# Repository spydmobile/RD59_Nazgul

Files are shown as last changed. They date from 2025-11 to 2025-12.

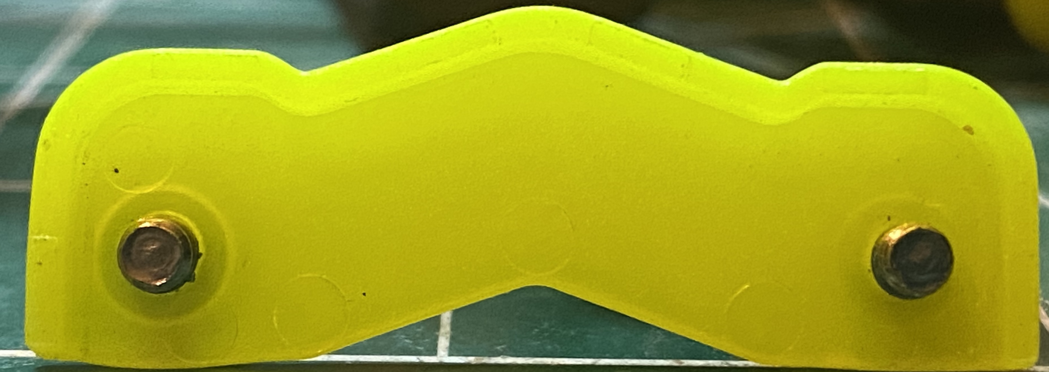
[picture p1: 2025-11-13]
custom parts/IMG_5613.jpg

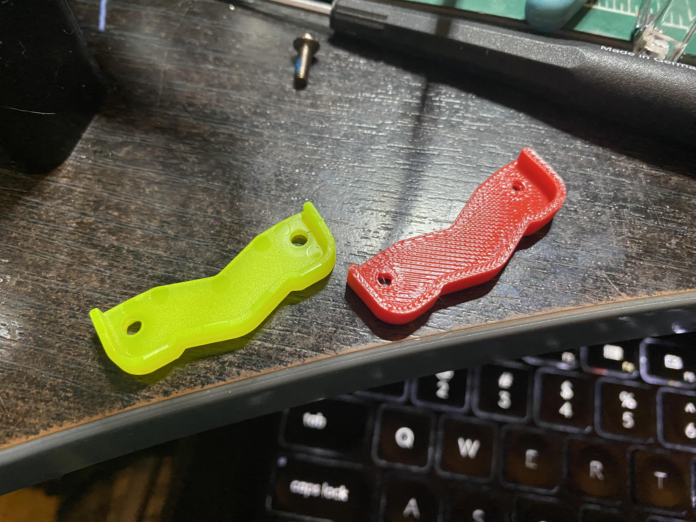
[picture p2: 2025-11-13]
custom parts/duped.jpg

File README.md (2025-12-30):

# RD-59 "Nazgul" Documentation Repository

**Drone Designator**: RD-59
**Code Name**: Nazgul
**Operator**: SpyD (Franco Nogarin)
**Platform**: Nazgul DC5 ECO V1.1 - 5" Freestyle Quadcopter

This repository serves as the **authoritative source of truth** for RD-59 "Nazgul" - a Nazgul DC5 ECO V1.1 acquired from Devon "Toasty" Felker on July 15, 2025.

---

## 🚨 Current Status

| Status | Value |
|---|---|
| **Airworthiness** | ❌ NOT AIRWORTHY (VTX swap in progress) |
| **VTX Status** | TX800 removed (Dec 30, 2025) - failed bench test Nov 14. Harness + antenna still installed. |
| **Next Step** | Install GEPRC RAD Mini 1W (on hand) |
| **Acquisition Date** | July 15, 2025 |
| **Test Flights** | 0 (not yet flown by current operator) |
| **Incidents** | 0 |
| **Modifications** | 1 completed (RX), 1 in progress (VTX swap), 2 pending |

---

## 📖 Origins

**Acquisition Story**:

This aircraft was purchased from **Devon "Toasty" Felker** in Hay River on **July 15, 2025** for **$273.12 CAD**.

The aircraft is a **Nazgul DC5 ECO V1.1** (iFlight pre-built 5" freestyle drone) that was sold as a **partial build**:

- **Removed by previous owner**: DJI O4 Air Unit Pro (camera + VTX)
- **Never included**: Receiver (not part of factory package)
- **Included**: Frame, flight controller, ESC, motors, GPS, props, battery connector

This is where RD-59 Nazgul's story with the current operator begins.

---

## 📚 Documentation

Complete technical documentation is maintained in the `/Documentation/` directory:

### 📋 Core Documents

- **[Documentation/README.md](./Documentation/README.md)** - Documentation hub and quick reference
- **[RD-59_AsBuilt_Parts_List.md](./Documentation/RD-59_AsBuilt_Parts_List.md)** - Current configuration and component inventory
- **[RD-59_Incident_Log.md](./Documentation/RD-59_Incident_Log.md)** - Crash reports and damage tracking
- **[RD-59_Modifications_Log.md](./Documentation/RD-59_Modifications_Log.md)** - Engineering changes and upgrades
- **[RD-59_Build_Timeline.md](./Documentation/RD-59_Build_Timeline.md)** - Project history and milestones

### 📖 Reference Materials

- **[Factory Specifications](./Documentation/reference/Nazgul_DC5_ECO_Factory_Specs.md)** - Original iFlight specifications

### 🔗 External Resources

- **Photo Gallery**: [Google Photos Album](https://photos.google.com/album/AF1QipMQ81SgmNKcywQYFzFxxncO6l4DfiegxZddzp05)
- **Local Photos**: `/Users/franconogarin/localcode/spyd.com/public/drone-lab/drones/RD-59/`

---

## 🎯 Quick Links

**Starting Point**: 👉 [**Documentation/README.md**](./Documentation/README.md)

**Need to know**:

- Current configuration? → [As-Built Parts List](./Documentation/RD-59_AsBuilt_Parts_List.md)
- Crash history? → [Incident Log](./Documentation/RD-59_Incident_Log.md)
- Modifications made? → [Modifications Log](./Documentation/RD-59_Modifications_Log.md)
- Project timeline? → [Build Timeline](./Documentation/RD-59_Build_Timeline.md)

---

## 🚀 Next Steps to Airworthiness

**Current State**: TX800 failed bench test (Nov 14) and removed (Dec 30). Camera, harness, and antenna remain installed. RAD Mini ready.

### Phase 1: Critical (VTX Swap)

1. ✓ **Install Receiver** (MOD-001) - HappyModel ELRS EP1 Dual RX - COMPLETE
2. ⚠️ **VTX Swap** (MOD-002A) - TX800 FAILED → GEPRC RAD Mini 1W
   - ✓ TX800 removed (Dec 30, 2025)
   - ✓ Ratel 2 camera installed
   - ✓ Harness + TrueRC antenna in place
   - ⏳ Install RAD Mini (rewire power from 5V to VBAT)
   - ⏳ Bench test video
   - ⏳ Bind ELRS receiver
3. **Test flights** - Establish baseline with analog system

### Phase 1B: Optional Digital Upgrade (If Analog Insufficient)

- **Walksnail Avatar HD** (MOD-002B) - on hand as backup if needed
- Trade-off: Better video quality, but 40-50% flight time penalty

### Phase 2: Optional Enhancements (After Flying)

1. *Optional*: Install RGB LEDs (MOD-003)
2. *Optional*: Install GPS-mate (MOD-004)

**Status**: RAD Mini on hand. Swap requires power wire move (5V → VBAT) then bench test.

See [Modifications Log](./Documentation/RD-59_Modifications_Log.md) for detailed installation checklists and analog vs digital comparison.

---

## ℹ️ Important Notes

- **Source of Truth**: This repository contains verified technical specifications
- **Partial Build**: Aircraft acquired without video system or receiver
- **RX Installed**: ELRS EP1 Dual RX installed Nov 13, 2025 - needs binding
- **VTX Swap In Progress**: TX800 failed (Nov 14) and removed (Dec 30). RAD Mini ready to install.
- **Untested**: Not yet flown by current operator since acquisition

---

## 📧 For Claude Code Assistants

See **[CLAUDE.md](./CLAUDE.md)** for detailed instructions on:

- Your role as RD-59 Archivist & SME
- Documentation standards and procedures
- How to work with the operator
- Repository structure and guidelines

---

**Repository Established**: November 10, 2025
**Maintained by**: SpyD (Franco Nogarin) with Claude Code

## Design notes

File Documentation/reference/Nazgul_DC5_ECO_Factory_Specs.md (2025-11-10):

# Nazgul DC5 ECO V1.1 6S HD O4 - Factory Specifications

**Reference Document**: Original factory specifications from iFlight

**Product Name**: Nazgul DC5 ECO 6S O4 HD - ELRS + GPS

---

## Overview

The Nazgul DC5 ECO is a 5-inch freestyle drone that redefines performance and value for money. Equipped with the DJI O4 Digital HD system, it delivers razor-sharp, propeller-free 4K video even in low light conditions. The robust carbon frame and aluminum camera mount guarantee durability without sacrificing lightness. The pre-installed GoPro mount makes the drone even more versatile.

Thanks to the BLITZ ATF435 flight controller and the powerful BLITZ E55S ESC, the Nazgul DC5 ECO offers a reliable and dynamic flying experience. With a maximum speed of 190 km/h and an optimized DeadCat design, this drone is perfect for FPV pilots looking for performance and quality.

---

## Features

- **4K Ultra HD video**: DJI O4 system with 1/1.3-inch sensor for stunning footage and stable 155° ultra-wide angle video
- **Robust and lightweight**: High-quality carbon frame with aluminum components for a stable construction
- **Anti-Spark technology**: Protects the electronics from power surges and extends the life of the XT60 connectors
- **Optimized DeadCat design**: No disturbing propellers in the camera image - ideal for professional aerial photography
- **Easy maintenance**: Built-in signaling devices and easily accessible components ensure convenient handling

---

## General Specifications

| Specification | Value |
|---|---|
| **Product name** | Nazgul DC5 ECO 6S O4 HD |
| **Geometry** | DeadCat (DC) |
| **Frame** | 240 mm wheelbase |
| **Weight** | 450g ±5g (without battery) |
| **Take-off weight** | Approx. 675g ±5g (with 6S 1480mAh battery) |
| **Dimensions (L×W×H)** | 193 × 144 × 34 mm |
| **Max. speed** | 190 km/h |
| **Max. hover time** | Approx. 7.5 minutes (6S 1480mAh, without load) |
| **Maximum flight altitude** | 7000 m |
| **Wind resistance** | Up to level 7 |
| **Temperature range** | -10 °C to 40 °C |

---

## Electronics

| Component | Specification |
|---|---|
| **Flight controller** | BLITZ ATF435 |
| **ESC** | BLITZ E55S 4-in-1 ESC |
| **Motors** | XING-E Pro 2207 1800KV |
| **Propeller** | Nazgul F5 |
| **GPS** | Yes |
| **Battery Connector** | XT60 with anti-spark technology |

---

## Video Transmission - DJI O4 Air Unit Pro

| Specification | Value |
|---|---|
| **Sensor** | 1/1.3-inch |
| **Video resolution** | 4K at 30fps, 1080p at 100fps |
| **Field of view (FOV)** | 155° |
| **Stabilization** | RockSteady 3.0+ |
| **Video Quality** | 1080P@100fps |
| **Max. video transmission range** | Up to 15 km (FCC) |
| **Operating frequencies** | 5.170-5.850 GHz |
| **Built-in memory** | 4GB |

---

## Package Contents

- 1 x Nazgul ECO
- 2 x Battery pads
- 2 x Nazgul F5 Prop (Pairs)

---

## Important Notes

**Factory Configuration**:
- This specification represents the drone as sold by iFlight
- Product includes DJI O4 Air Unit Pro as standard
- GPS module included
- **Receiver NOT included** - must be purchased separately

**RD-59 As-Purchased**:
- DJI O4 system was removed by previous owner before sale
- No receiver was ever installed (not included by factory)
- See `RD-59_AsBuilt_Parts_List.md` for actual acquired configuration

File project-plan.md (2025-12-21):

# Project Plan: RD59 Nazgul

**Project:** RD59_Nazgul
**Owner:** Circuit (Fleet Steward)
**Created:** December 21, 2025
**Status:** Not Airworthy (Missing Critical Systems)

---

## Overview

RD59 "Nazgul" is a 5" freestyle quad acquired as a partial build. The DJI O4 video system was removed by the previous owner, and no receiver was ever installed. Critical systems pending installation.

**Repository:** `spydmobile/RD59_Nazgul`
**Location:** `projects/drone_management/drones/RD59_Nazgul/`
**Platform:** 5" Freestyle (iFlight Nazgul DC5 ECO V1.1)

---

## Current State

| Attribute | Value |
|---|---|
| **Airworthiness** | NOT AIRWORTHY |
| **Acquisition Date** | July 15, 2025 |
| **Days Since Acquisition** | 159 days |
| **Previous Owner** | Devon "Toasty" Felker |
| **Flight Hours (Current Owner)** | 0.0 |
| **Video System** | REMOVED (was DJI O4) |
| **Control Link** | NOT INSTALLED |

**Operational Components:**
- Frame (Nazgul DC5 240mm DeadCat)
- FC (BLITZ ATF435 - untested)
- ESC (BLITZ E55S 4-in-1 60A - untested)
- Motors (XING-E Pro 2207 1800KV x4 - untested)
- GPS (iFlight - operational)
- Props (Nazgul F5)

**Missing Components:**
- Receiver (never included)
- Video system (stripped by previous owner)

---

## Milestones

### Milestone 1: Acquisition (COMPLETE)
**Status:** Complete | **Date:** July 15, 2025

- [x] Purchased from Devon Felker
- [x] Documented as-received condition
- [x] Created documentation structure
- [x] Photographed aircraft

### Milestone 2: Phase 1 Parts (COMPLETE)
**Status:** Complete | **Date:** July 24, 2025

Parts on hand, installation pending.

- [x] Order ELRS receiver (HappyModel EP1 Dual)
- [x] Order analog VTX (SpeedyBee TX800)
- [x] Order analog camera (CADDX Ratel 2)
- [x] Parts received

### Milestone 3: Phase 1 Installation (PENDING)
**Status:** Pending | **Priority:** CRITICAL

Get aircraft flying with analog video for maximum flight time.

- [ ] Install HappyModel ELRS EP1 Dual receiver (MOD-001)
- [ ] Install SpeedyBee TX800 VTX (MOD-002A)
- [ ] Install CADDX Ratel 2 camera
- [ ] Route antennas
- [ ] Configure Betaflight
- [ ] Bind ELRS receiver
- [ ] Bench test all systems
- [ ] First hover test
- [ ] Maiden FPV flight

### Milestone 4: Phase 1B Digital Upgrade (OPTIONAL)
**Status:** Optional | **Priority:** Low

Only if analog insufficient after test flights.

- [ ] Evaluate analog performance
- [ ] Decision: Keep analog or upgrade?
- [ ] If upgrade: Install Walksnail Avatar HD Moonlight (MOD-002B)
- [ ] Note: Digital reduces flight time (5-7 min → 3-5 min)

### Milestone 5: Phase 2 Enhancements (PENDING)
**Status:** Pending | **Priority:** Low

Install after test flights prove platform viability.

- [ ] Install SpeedyBee RGB LEDs (MOD-003)
- [ ] Install VIFLY GPS-mate with Finder 2 (MOD-004)

---

## GitHub Issues

| # | Title | Labels | Priority |
|---|---|---|---|
| 1 | Install HappyModel ELRS EP1 Dual RX receiver | pending-install, radio-system | CRITICAL |
| 2 | Select and install replacement FPV video system | enhancement, video-system | CRITICAL |

---

## Current Tasks

| Task | Priority | Status |
|---|---|---|
| Install ELRS receiver | CRITICAL | Parts in hand |
| Install analog VTX/camera | CRITICAL | Parts in hand |
| Betaflight configuration | High | After installation |
| First flight test | High | After config |
| Evaluate analog performance | Medium | After flights |

---

## Installation Strategy

**Phase 1: Minimum Viable Aircraft**
1. Install receiver (ELRS EP1 Dual) - control link
2. Install analog VTX (TX800) + camera (Ratel 2) - video link
3. Get flying, evaluate performance

**Why Analog First:**
- Longer flight time (5-7 min vs 3-5 min with digital)
- Lower power consumption
- Parts already on hand
- Can upgrade later if needed

**Phase 1B Decision Point:**
After 5-10 test flights, evaluate:
- Is analog video quality acceptable?
- Is 5-7 min flight time sufficient?
- If no: upgrade to Walksnail (MOD-002B)

---

## Operations

**Documentation:**
- Parts List: `Documentation/RD-59_AsBuilt_Parts_List.md`
- Timeline: `Documentation/RD-59_Build_Timeline.md`
- Modifications: `Documentation/RD-59_Modifications_Log.md`
- Installation Guide: `Documentation/RD-59_Phase1_Installation_Guide.md`

**Pre-acquisition history:**
- Previous owner flight history: Unknown
- Previous incidents: Unknown
- All electronics untested by current operator

---

*Circuit - Fleet Steward*

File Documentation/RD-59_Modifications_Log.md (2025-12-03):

# RD-59 "Nazgul" Modifications Log

**Drone Designator**: RD-59
**Code Name**: Nazgul
**Operator**: SpyD (Franco Nogarin)
**Last Updated**: 2025-12-02

---

## Modification Summary

| Total Modifications | Last Modification Date | Current Status |
|---|---|---|
| **1 completed, 1 in progress, 3 pending** | GEPRC RAD arrived Dec 2, 2025 | Analog video confirmed |

**Installation Plan**:

- **Phase 1 (Critical)**: MOD-001 (✅ installed) + MOD-002A (analog - GEPRC RAD) → Get aircraft flying
- **Phase 1B (Backup Only)**: MOD-002B (Walksnail) → Only if analog performance insufficient
- **Phase 2 (Optional Enhancements)**: MOD-003 + MOD-004 → Add LEDs and GPS-mate after baseline established

**Decision (Dec 2, 2025)**: HDZero VTX (MOD-002C) reallocated to RD-54 "Zorro". RD-59 confirmed for analog to maximize flight time.

---

## Planned Modifications

### PHASE 1: CRITICAL AIRWORTHINESS INSTALLATIONS

**Objective**: Install receiver and video system to achieve minimum flight capability

### MOD-001: ELRS Receiver Installation

**Status**: 🟢 **COMPLETED** - Installed November 13, 2025
**Type**: Initial Installation
**Priority**: CRITICAL (required for airworthiness)
**Parts Acquired**: June 4, 2025 (already owned before drone acquisition)
**Installation Date**: November 13, 2025

#### Description

Installation of ExpressLRS receiver system to enable aircraft control.

#### Modification Details

| Item | Original Config | Modified Config |
|---|---|---|
| **Receiver** | None (never included) | HappyModel ExpressLRS TCXO EP1 Dual RX |
| **Control Link** | None | ExpressLRS 2.4GHz |
| **Antenna** | None | Included with EP1 Dual RX |

#### Rationale

- Aircraft was purchased without receiver (not included in factory package)
- Receiver is critical component for aircraft control
- ELRS selected for low latency, long range, and reliability
- EP1 Dual RX provides redundancy with dual antenna diversity
- Already owned this receiver prior to acquiring RD-59

#### Expected Impact

- Enable aircraft control capability
- Required for test flights
- Minimal weight impact (~1-2g)
- Dual receiver provides improved range and reliability

#### Parts On Hand

- [x] HappyModel ExpressLRS TCXO EP1 Dual RX (acquired June 4, 2025)
- [x] Antennas (included with receiver)

#### Installation Checklist

**UART Selection** (from BLITZ ATF435 wiring diagram):

- **Recommended**: UART2 (R2/T2 pads) - shown in diagram for ELRS receiver
- **Alternative UARTs available**: UART1 (R1/T1), UART3 (R3/T3), UART4 (R4/T4), UART5 (R5/T5), UART6 (R6)

**Wiring Connections**:

- [ ] Solder RX wire to T2 pad (FC transmits to receiver)
- [ ] Solder TX wire to R2 pad (FC receives from receiver)
- [ ] Solder VCC wire to 5V pad (receiver power)
- [ ] Solder GND wire to GND pad (ground)

**Physical Installation**:

- [ ] Determine mounting location (typically between FC and camera mount)
- [ ] Mount HappyModel EP1 Dual RX receiver with double-sided tape or heat shrink

**Dual Antenna Routing Strategy**:

The HappyModel EP1 Dual RX has two T-shaped antennas for diversity reception. The Nazgul was originally designed for DJI O4's antenna configuration, so custom routing is required for optimal dual-antenna diversity.

**Critical Antenna Diversity Principles**:

- ✅ **90° separation**: Antennas must be perpendicular to each other (NOT parallel)
- ✅ **Physical separation**: Mount at different locations on frame
- ✅ **Minimize carbon fiber contact**: CF blocks 2.4GHz signal - maintain 5-10mm clearance minimum
- ✅ **Secure firmly**: Heat shrink/zip ties prevent antenna movement into props
- ✅ **Top mounting preferred**: Less carbon fiber interference than bottom mounting
- ❌ **Never parallel**: Defeats dual diversity purpose
- ❌ **Never touching carbon fiber**: Causes major signal degradation

**Primary Antenna (Antenna 1) - Rear Vertical**:

- [ ] Route through rear of frame (where DJI O4 antenna previously exited, or near GPS)
- [ ] Position **vertically** or angled back/up at 30-45° (perpendicular to drone body)
- [ ] Use existing antenna mount hole if available, or create exit point
- [ ] Heat shrink antenna base to frame standoff or rear for stability
- [ ] Ensure antenna extends beyond frame and clears carbon fiber by 5-10mm minimum

**Secondary Antenna (Antenna 2) - Rear Side Top (RECOMMENDED)**:

**Option 3: Rear Side Top** ✅ **BEST CONFIGURATION**

- [ ] Mount T-antenna **horizontally** (parallel to drone body) on top of frame
- [ ] Position beside or slightly forward of VTX location
- [ ] Maintain **10-15mm clearance from VTX** to minimize RF interference
- [ ] Orient T-antenna so it's **perpendicular to primary antenna** (90° diversity)
- [ ] Ensure antenna tips **do not touch carbon fiber arms** (maintain 5-10mm gap)
- [ ] Use heat shrink or small zip tie to secure to frame standoff or top plate
- [ ] Verify antenna tips have clearance from props during flight

**Why Option 3 (Rear Side Top) is Optimal**:

- Top mounting = minimal carbon fiber interference (best signal propagation)
- Rear location = away from front props (DeadCat has most prop activity forward)
- Physical separation from primary antenna = improved diversity
- Horizontal T gives 90° diversity from vertical primary
- Less vulnerable to ground strikes vs bottom mounting
- Good separation from electrical noise sources (ESC/battery)

**Alternative Options Evaluated** (use only if Option 3 not feasible):

*Option 1: Side Bottom (Under FC)* - ❌ **NOT RECOMMENDED**

- Antenna tips touch CF arms = major signal loss
- Maximum carbon fiber interference
- Vulnerable to ground strikes

*Option 2: Side Top (Above FC, between arms)* - ⚠️ **MARGINAL**

- Better than bottom, but antenna tips still touch/near CF arms
- Props directly above = turbulence/strike risk

*Option 4: Rear Side Bottom (Under VTX)* - ❌ **NOT RECOMMENDED**

- Carbon fiber interference from bottom mounting
- Ground strike vulnerability
- Near battery/ESC electrical noise

**Final Antenna Installation Verification**:

- [ ] Verify 90° separation between primary (vertical) and secondary (horizontal) antennas
- [ ] Verify both antenna tips clear carbon fiber by 5-10mm minimum
- [ ] Verify neither antenna can reach prop paths during flight
- [ ] Verify antennas are secured and cannot move/vibrate loose
- [ ] Verify secondary antenna has 10-15mm clearance from VTX
- [ ] Take photos of final antenna routing for documentation

**Configuration & Testing**:

- [ ] Enable UART3 in Betaflight Ports tab
- [ ] Configure UART3 for Serial RX
- [ ] Set receiver protocol to CRSF (ExpressLRS)
- [ ] Bind receiver to transmitter
- [ ] Test control inputs (roll/pitch/yaw/throttle)
- [ ] Configure and test failsafe settings
- [ ] Verify signal strength and range (bench test)
- [ ] Verify RSSI display on OSD
- [ ] Update RD-59_AsBuilt_Parts_List.md

#### Installation Results (Completed November 13, 2025)

**UART Configuration:**

- ✅ **UART3 used** (R3/T3 pads) instead of recommended UART2
- Operator chose UART3 over UART2 (both equally valid for ELRS)

**Wiring Completed:**

- ✅ EP1 RX (blue wire) → FC T3 pad
- ✅ EP1 TX (blue wire with yellow ends) → FC R3 pad
- ✅ EP1 5V (red wire) → FC 5V pad
- ✅ EP1 GND (red wire with black ends) → FC GND pad
- Wire gauge: 24AWG silicone (signal wires), 24AWG stranded non-silicone (power)
- Wires twisted in pairs for EMI reduction
- All wires pre-tinned, soldered, and heat-shrunk

**Physical Installation:**

- ✅ EP1 receiver wrapped in heat shrink for protection
- ✅ Hot glued into Nazgul receiver bracket (reused DJI O4 mount)
- Mounting location: Original DJI receiver position

**Antenna Routing (Final Configuration):**

*Primary Antenna (Antenna 1):*

- ✅ **Horizontal orientation** (parallel to drone body)
- ✅ Rear exit
- ✅ **17.5mm clearance from carbon fiber** (exceeds 5-10mm spec)

*Secondary Antenna (Antenna 2):*

- ✅ **Vertical orientation** (up/down)
- ✅ Side position behind VTX
- ✅ **4mm clearance from carbon body** (marginal - just under 5mm spec)

**Diversity Configuration:**

- ✅ **90° separation achieved** (horizontal primary vs vertical secondary)
- ✅ Physical separation (rear vs side)
- ✅ Both antennas secured

**Deviations from Plan:**

- Changed from UART2 to UART3 (operator preference)
- Primary antenna horizontal instead of vertical (adapted to actual frame geometry)
- Secondary antenna vertical side mount (not rear side top Option 3, but still achieves 90° diversity)

**Notes:**

- No issues during soldering
- Photos taken of installation
- Configuration and binding deferred to next session

---

### MOD-002A: Analog Video System Installation (Initial)

**Status**: 🔵 **IN PROGRESS** - Hardware installed Nov 13, 2025; bench test FAILED Nov 14, 2025
**Type**: Initial Installation
**Priority**: CRITICAL (required for FPV operation)
**Parts Status**: Already owned (liberated from 3.5" build)
**Installation Date**: November 13, 2025
**Bench Test Date**: November 14, 2025
**Bench Test Result**: ❌ FAILED - VTX communication working, but no video output; excessive heat

#### MOD-002A Description

Installation of analog FPV system (SpeedyBee TX800 + CADDX Ratel 2) as initial video system to get aircraft flying quickly.

#### MOD-002A Modification Details

| Item | Original Config | Modified Config |
|---|---|---|
| **Video System** | DJI O4 Air Unit Pro (Digital HD) | Analog (TX800 + Ratel 2) |
| **Camera** | DJI O4 1/1.3" sensor, 155° FOV | CADDX Ratel 2 (red) |
| **VTX** | DJI O4 (5.170-5.850 GHz, 15km range) | SpeedyBee TX800 (5.8GHz, 25-800mW) |
| **Recording** | DJI O4 4GB onboard | None (analog) |

#### MOD-002A Rationale

- **Test with what's already owned**: TX800 and Ratel 2 already on hand (liberated from 3.5" build)
- **Get flying quickly**: Analog is lighter and faster to install
- **Better flight time**: ~5-7 min vs 3-5 min with digital (40-50% improvement)
- **Lighter weight**: ~25g vs ~70g for digital (45g savings)
- **Lower power draw**: ~1A vs ~2.5A for digital
- **Evaluate needs**: Test analog performance before committing to digital
- **TX800 redemption**: Previous underperformance on 3.5" suspected due to mounting without standoffs (shorting issues)
- **Proper installation this time**: Will use standoffs to prevent shorting as per manual

#### MOD-002A Expected Impact

- Enable FPV video capability (analog quality)
- Flight time: **5-7 minutes** freestyle (excellent)
- Range: **2-4km** at 800mW (sufficient for most flying)
- Weight impact: **+25g** (minimal)
- Power draw: **~1A** at 800mW (low)
- No onboard recording (trade-off for flight time)

#### MOD-002A Performance Comparison vs Digital

| Metric | Analog (MOD-002A) | Digital (MOD-002B) | Advantage |
|---|---|---|---|
| Weight | +25g | +70g | Analog: 45g lighter |
| Power | ~1A | ~2.5A | Analog: 1.5A less |
| Flight Time | 5-7 min | 3-5 min | Analog: +40-50% |
| Range | 2-4km | 3-6km | Digital: slightly better |
| Video Quality | Standard analog | HD digital | Digital: much better |
| Recording | No | Yes (HD) | Digital wins |
| Cost | $0 (owned) | $0 (owned) | Tie |

**Decision**: Start with analog, evaluate if digital upgrade is worth the flight time penalty

#### MOD-002A Parts On Hand

- [x] SpeedyBee TX800 VTX (liberated from 3.5" build)
- [x] CADDX Ratel 2 camera (red) (already owned)
- [x] VTX antenna (included with TX800)

#### MOD-002A Installation Checklist

**Pre-Installation Testing**:

- [ ] Bench test TX800 to verify not damaged from previous shorting issues
- [ ] Prepare TX800 mounting with proper standoffs (CRITICAL - avoid shorting!)
- [ ] Verify TX800 antenna connector is intact

**UART Selection for VTX Control** (from BLITZ ATF435 wiring diagram):

- **Recommended**: UART1 (R1/T1 pads) or UART3 (R3/T3 pads) for SmartAudio/Tramp
- **Note**: UART2 already reserved for ELRS receiver (MOD-001)
- **Alternative UARTs**: UART4 (R4/T4), UART5 (R5/T5), UART6 (R6) if needed

**Camera Installation**:

- [ ] Install camera mount on front of frame
- [ ] Mount CADDX Ratel 2 camera with appropriate angle (20-40° typical for freestyle)
- [ ] Wire camera to TX800 VTX (camera video out → VTX video in)

**VTX Installation**:

- [ ] Install TX800 VTX with standoffs (CRITICAL - prevents shorting to FC or frame)
- [ ] Verify standoffs provide clearance from all metal surfaces
- [ ] Position VTX for easy antenna access

**Wiring Connections - VTX to FC**:

- [ ] Solder VTX TX wire to R1 pad (for SmartAudio/Tramp control)
- [ ] Solder VTX RX wire to T1 pad (if bidirectional control needed)
- [ ] Solder VTX power (+) wire to VBAT pad (filtered battery voltage)
- [ ] Solder VTX ground (-) wire to GND pad

**Antenna & Finalization**:

- [ ] Route and secure VTX antenna away from carbon fiber
- [ ] Ensure antenna has clear path (not blocked by frame/props)
- [ ] Secure all wiring with heat shrink/tape
- [ ] Verify no wires touching propeller path

**Configuration & Testing**:

- [ ] Enable UART1 in Betaflight Ports tab
- [ ] Configure UART1 for VTX (SmartAudio/Tramp/IRC Tramp)
- [ ] Configure VTX table in Betaflight (5.8GHz bands/channels)
- [ ] Configure OSD layout (add battery voltage, RSSI, flight time, etc.)
- [ ] Test video feed with analog goggles
- [ ] Verify OSD elements display correctly
- [ ] Test VTX power level switching (25/200/800mW)
- [ ] Verify VTX channel/band switching via OSD
- [ ] Update RD-59_AsBuilt_Parts_List.md

#### Installation Results (Completed November 13, 2025)

**Camera Mount - Custom TPU V3:**

- ✅ Reverse-engineered Nazgul bumper from photos (GIMP → Inkscape → Bambu Slicer)
- ✅ Integrated with Printables Ratel 2 protective sleeve
- ✅ Built-in 15° compensation wedge for camera angle
- ✅ **Net camera angle: ~10° upward** (cruising configuration)
- ✅ Material: Bambu TPU (red), X1C + AMS, 0.16mm HQ, solid 4-wall construction
- ✅ Fits perfectly in aluminum DJI housing
- Source: https://www.printables.com/model/1339078-caddx-ratel-2-crash-protection-sleeve-tpu

**Hardware Installed:**

- ✅ CADDX Ratel 2 camera (red) - mounted in V3 custom bumper
- ✅ SpeedyBee TX800 VTX (5V powered, 3.7-5V input range)
- ✅ TrueRC CORE 85mm MMCX RHCP antenna (replaces damaged RD-53 antenna)

**Wiring Harness (Camera + VTX → FC):**

- ✅ Camera Red → FC 5V
- ✅ Camera Black → FC GND
- ✅ VTX Red → FC 5V (**NOT VBAT!** TX800 is 3.7-5V only)
- ✅ VTX Black → FC GND
- ✅ VTX Green (IRC Tramp RX) → FC T1 (UART1 TX)
- ✅ Wires: 24AWG, twisted, tinned, soldered, heat-shrunk
- ✅ Routed over top of FC (more room than between layers)

**VTX Antenna:**

- ✅ TrueRC CORE 85mm MMCX RHCP
- ✅ Mounted 45° angle out rear
- ✅ Custom TPU threaded screw mount (repurposed dual antenna hole)

**Physical Installation Status:**

- ✅ Soldering complete
- ✅ Camera/VTX mounted
- ✅ Antenna secured

#### Bench Test Results (November 14, 2025)

**Test Environment:**

- FC: BLITZ ATF435 running Betaflight 4.5.1 (released Jan 16, 2025)
- Power: USB only (5V)
- Goggles: Analog FPV goggles (testing on Raceband)
- Software: Betaflight Configurator 10.10.0

**Betaflight Configuration Steps:**

1. ✅ **Initial connection**: FC detected as IFLIGHT_BLITZ_F435
2. ✅ **Accelerometer calibration**: Completed successfully
3. ✅ **UART inspection**: Discovered old DJI O4 configuration still present
   - UART1 (serial 0) was set to VTX (MSP + Displayport) - DJI digital config
   - UART3 (serial 2) already configured for Serial RX (CRSF) - correct for ELRS
4. ✅ **VTX Table configuration**: Configured via CLI
   - 5 bands (Boscam A, B, E, Fatshark, Raceband)
   - 8 channels per band
   - 4 power levels: 25mW (PIT), 200mW, 400mW, 800mW (MAX)
   - Initial settings: Raceband 1 (5658MHz), Pit mode (25mW)
5. ❌ **UART1 protocol issue**: Initial config used wrong VTX protocol
   - CLI command attempted generic VTX (function 2048)
   - Should have been **VTX (IRC Tramp)** specifically
   - Corrected via Ports tab in Betaflight Configurator
6. ✅ **VTX communication established**: "Device ready: True" after correct protocol set
7. ❌ **Video output FAILED**: No video signal in goggles despite VTX communication working

**Problems Discovered:**

1. **VTX ran at full power initially (before pit mode config)**
   - Default VTX config had no power limits
   - VTX likely running at 800mW on USB before configuration
   - TX800 became **extremely hot** during initial USB connection
   - Heat persisted even after pit mode (25mW) configuration

2. **No video output**
   - VTX communication with FC: ✅ Working (IRC Tramp, Device ready: True)
   - VTX LED status: Red/blue flashing 1 per second (indicates no video input from camera)
   - Goggles: No video signal on Raceband 1 (R1 - 5658MHz)
   - Tested at 200mW on R8: Still no video signal
   - VTX antenna connected throughout testing (no RF damage)

3. **Excessive heat**
   - TX800 running dangerously hot even supposedly in pit mode (25mW)
   - Heat excessive even when "doing nothing"
   - LED indicators blocked by heatsink (poor design - can't clearly see status)
   - VTX temperature abnormal for USB-powered pit mode operation

**Troubleshooting Performed:**

- ✅ Verified UART1 configured for IRC Tramp protocol (not SmartAudio, not MSP)
- ✅ Verified VTX table configured correctly (bands, channels, power levels)
- ✅ Verified VTX communication working (Device ready: True in Betaflight)
- ✅ Verified antenna connected (no RF damage)
- ✅ Verified wiring connections (JST harness built Nov 13, all connections correct)
- ✅ Attempted manual VTX mode button (behavior inconsistent, LEDs blocked by heatsink)
- ❌ Unable to isolate root cause of no video output
- ❌ Unable to resolve excessive heat issue

**Root Cause Analysis:**

**Likely causes of no video:**

1. Camera not providing video signal to VTX (most likely based on red/blue LED pattern)
2. Possible camera power issue (though wired correctly to 5V/GND)
3. Possible video wire issue (though JST harness verified correct)
4. VTX internal fault (cannot rule out)

**Root cause of excessive heat:**

1. VTX drawing excessive current even in pit mode (abnormal)
2. Possible VTX internal fault/damage
3. Possible short or incorrect power configuration (though wired to 5V as per spec)

**Operator Assessment:**

- **TX800 problematic from day 1**: Operator has not been happy with TX800 since acquisition
- **Poor design**: LEDs blocked by heatsink, cannot clearly see status indicators
- **Excessive heat concerning**: VTX should not run this hot on USB power in pit mode
- **Previous performance issues**: TX800 underperformed on 3.5" build (suspected shorting without standoffs)
- **Trust lost**: Combination of heat, no video, and day-1 frustration = low confidence in component

**Test Result**: ❌ **BENCH TEST FAILED**

**Status**: Aircraft remains **NOT AIRWORTHY** - no video system operational

**Next Steps**: Operator evaluating VTX replacement options (see below)

#### VTX Replacement Consideration

**TX800 Issues Summary:**

- Excessive heat (abnormal for pit mode on USB)
- No video output (despite VTX communication working)
- LEDs blocked by heatsink (poor design)
- Operator unhappy since day 1
- Previous underperformance on 3.5" build
- Low confidence in reliability

**Replacement Options Evaluated:**

1. **Different analog VTX** (Rush Tank, TBS Unify, GEPRC RAD, etc.)
   - Allows continued analog testing for flight time evaluation
   - Known-good hardware for baseline testing
   - Lower cost than digital

2. **Wait for HDZero** (on order Nov 2, 2025 - $829.98, expected ~Nov 9-15)
   - Skip analog entirely
   - Move directly to digital HD system
   - Aligns with strategic fleet transition evaluation
   - Trade-off: Reduced flight time vs analog (4-6 min vs 5-7 min)

3. **Install Walksnail** (already on hand from July 24, 2025)
   - Digital HD with onboard recording
   - Compatible with existing Goggles X
   - Trade-off: Reduced flight time (3-5 min vs 5-7 min analog)

4. **ArduPilot mapping platform rebuild** (evaluated and rejected)
   - 5" frame unsuitable for mapping (severe vibration/jello issues)
   - Would require 7" long-range frame for proper mapping work
   - Mapping platform will be separate project (future build)
   - RD-59 remains FPV cruiser on Nazgul frame

**Decision Made (November 14, 2025):**

**VTX Replacement: GEPRC RAD Mini 1W** ($74)

**Rationale:**
- Operator already happy with GEPRC RAD from other builds
- Proven analog VTX with good performance
- Maximizes flight time for cruiser role (5-7 min expected)
- IRC Tramp protocol (Betaflight already configured for this)
- Lower cost than digital options
- Allows baseline analog testing as originally planned
- RD-59 remains manual FPV cruiser (not mapping platform)

**Strategic Context:**
- RD-53 and RD-54 already cover manual FPV flying
- RD-59 adds to FPV fleet as cruiser (10° camera angle, long flight time)
- HDZero system (on order) allocated to RD-54 for performance flying
- Professional mapping platform will be separate future build (7" frame, ArduPilot)

**Next Steps:**
- ✅ ~~Order GEPRC RAD Mini 1W ($74)~~ - ORDERED
- ✅ ~~GEPRC RAD Mini 1W delivered~~ - ARRIVED Dec 2, 2025
- [ ] Remove failed TX800
- [ ] Install GEPRC RAD (reuse existing Ratel 2 camera and wiring harness)
- [ ] Bench test video system
- [ ] Bind ELRS receiver
- [ ] Complete MOD-002A

**Modification Status**: MOD-002A remains **IN PROGRESS** - GEPRC RAD on hand, ready for installation

---

### MOD-002B: Walksnail Avatar HD Upgrade (Optional Path 1)

**Status**: 🔵 **OPTIONAL** - Parts on hand, install only if MOD-002A performance insufficient
**Type**: Upgrade
**Priority**: LOW (upgrade from analog if needed)
**Parts Ordered**: July 17, 2025
**Parts Delivered**: July 24, 2025

#### Description

Optional upgrade to Walksnail Avatar HD Moonlight VTX Kit if analog performance proves insufficient.

#### When to Consider This Upgrade

- Analog range (2-4km) is insufficient for desired flying style
- HD video quality desired for review/progression
- Onboard HD recording needed
- Willing to accept 40-50% flight time reduction for better video
- Already own Goggles X (Walksnail compatible)

#### Modification Details

| Item | MOD-002A Config (Analog) | MOD-002B Config (Walksnail) |
|---|---|---|
| **Video System** | SpeedyBee TX800 (analog) | Walksnail Avatar HD Moonlight |
| **Camera** | CADDX Ratel 2 | Walksnail Moonlight camera |
| **VTX** | TX800 (5.8GHz, 800mW) | Walksnail Avatar VTX (digital) |
| **Recording** | None | HD onboard recording |
| **Goggles** | Any analog goggles | Goggles X (already owned) |

#### Rationale (If Upgrade Needed)

- **Walksnail over DJI**: Operator exited DJI ecosystem ($10k investment)
- **Goggles X compatibility**: Considerable investment already made
- **HD recording**: Important for post-flight review
- **Better range**: 3-6km vs 2-4km analog
- **Digital HD quality**: Superior to analog

#### Expected Impact (vs Analog)

- Better video quality (HD digital)
- Onboard HD recording capability
- Slightly better range (3-6km vs 2-4km)
- **Flight time penalty**: 3-5 min vs 5-7 min (40-50% reduction)
- **Weight penalty**: +45g heavier than analog
- **Power penalty**: +1.5A more draw than analog

#### Parts On Hand

- [x] Walksnail Avatar HD Moonlight VTX Kit (delivered July 24, 2025)
- [x] Moonlight camera (included in kit)
- [x] VTX module (included in kit)
- [x] Antennas (included in kit)

#### Installation Checklist (If Proceeding)

- [ ] Remove TX800 and Ratel 2 (save as spares)
- [ ] Install Walksnail camera mount
- [ ] Mount Moonlight camera
- [ ] Install Walksnail VTX module
- [ ] Wire camera to VTX
- [ ] Wire VTX to FC (UART for MSP)
- [ ] Wire VTX to power (VBAT/GND)
- [ ] Route and secure VTX antenna
- [ ] Configure MSP in Betaflight
- [ ] Configure OSD layout
- [ ] Test video feed with Goggles X
- [ ] Test HD recording functionality
- [ ] Verify VTX power level and channel
- [ ] Update RD-59_AsBuilt_Parts_List.md

**Decision Point**: Only proceed with this upgrade if analog testing reveals insufficient performance

---

### MOD-002C: HDZero Freestyle V2 Upgrade (REALLOCATED TO RD-54)

**Status**: ➡️ **REALLOCATED** - VTX allocated to RD-54 "Zorro" (Dec 2, 2025)
**Type**: Upgrade
**Priority**: N/A (no longer applicable to RD-59)
**Parts Ordered**: November 2, 2025
**Parts Arrived**: December 2, 2025
**Reallocation Decision**: December 2, 2025

#### Description

~~Alternative digital upgrade path using HDZero Freestyle V2 system.~~ **REALLOCATED**: HDZero VTX allocated to RD-54 "Zorro" for HDZero ecosystem evaluation. RD-59 confirmed for analog (MOD-002A) to maximize flight time for cruiser role.

#### When to Consider This Upgrade

- **Primary use case**: Operator wants HDZero to become daily driver goggles for FPV fleet
- Analog range (2-4km) is insufficient for desired flying style
- Lower latency preferred over maximum video quality (key HDZero advantage)
- HD video quality desired but not at expense of responsiveness
- Onboard HD recording needed
- Evaluating HDZero ecosystem for potential fleet-wide transition from Walksnail

#### Modification Details

| Item | MOD-002A Config (Analog) | MOD-002C Config (HDZero) |
|---|---|---|
| **Video System** | SpeedyBee TX800 (analog) | HDZero Freestyle V2 |
| **Camera** | CADDX Ratel 2 | HDZero camera (included in kit) |
| **VTX** | TX800 (5.8GHz, 800mW) | HDZero VTX (digital) |
| **Recording** | None | HD onboard recording |
| **Goggles** | Any analog goggles | HDZero Goggle 2 (red, with Echo antenna kit) |

#### Rationale (If Upgrade Needed)

- **Transitioning to HDZero as primary ecosystem**: Want HDZero Goggle 2 to become daily driver goggles
- **Current fleet context**:
  - DJI: Mini Pro 4 complete setup (Motion, Goggles, screen remote) - cinematic/AP platform
  - Walksnail: Goggles X + multiple drones with Avatar VTX - current FPV fleet
    - RD-54 "Zorro" (Walksnail Avatar VTX)
    - RD-55 "Flylens75" (Walksnail Avatar VTX)
    - RD-59 "Nazgul" (Walksnail Avatar HD Moonlight available, not installed)
  - HDZero: New to ecosystem, evaluating for FPV transition
- **Lower latency advantage**: HDZero known for better responsiveness than Walksnail/DJI
- **Strategic investment**: $829.98 to evaluate HDZero as replacement for Goggles X across 3-aircraft FPV fleet
- **RD-59 as test platform**: Evaluate HDZero here before potentially converting RD-54 & RD-55 from Walksnail
- **Fleet-wide decision**: If HDZero succeeds on RD-59, may retrofit RD-54 & RD-55 with HDZero VTXs
- **HD recording**: Important for post-flight review
- **Ecosystem diversification**: Separate cinematic (DJI) from FPV racing/freestyle (HDZero target)

#### Expected Impact (vs Analog)

- Better video quality (HD digital, lower latency than Walksnail)
- Onboard HD recording capability
- Range comparable to Walksnail (3-6km estimated)
- **Flight time**: 4-6 min (better than Walksnail, lighter than original DJI O4)
- **Weight advantage over O4**: HDZero (~45-50g) vs DJI O4 (~70g) = ~20-25g lighter
- **Power draw**: ~1.5-2A (less than Walksnail's ~2.5A)
- **No action cam**: Build stays light without GoPro/action cam weight

#### HDZero vs Walksnail Comparison

| Characteristic | HDZero Freestyle V2 | Walksnail Avatar HD Moonlight |
|---|---|---|
| **Latency** | Lower (known for responsiveness) | Higher than HDZero |
| **Video Quality** | Good HD quality | Excellent HD quality |
| **Recording** | HD onboard | HD onboard |
| **Range** | 3-6km (estimated) | 3-6km |
| **Ecosystem Cost** | $829.98 (goggles + VTX) | Already own Goggles X + multiple Avatar VTXs |
| **Fleet Strategy** | Evaluating as Goggles X replacement | Current FPV fleet standard |
| **Flight Time** | 4-6 min (lighter than O4) | 3-5 min |
| **Weight** | ~45-50g (lighter than O4) | ~70g |
| **Power Draw** | ~1.5-2A | ~2.5A |

#### Parts Status

- [x] HDZero Goggle 2 (red) with Echo Antenna Kit - $679.99 (arrived Dec 2, 2025)
- [x] HDZero Freestyle V2 Kit - $149.99 (arrived Dec 2, 2025) - **➡️ REALLOCATED TO RD-54**

**Reallocation Note (Dec 2, 2025)**: HDZero VTX allocated to RD-54 "Zorro". Goggles remain available for use with RD-54 (HDZero) or other future HDZero aircraft.

#### Installation Checklist (If Proceeding)

- [ ] Receive and inventory HDZero parts
- [ ] Remove TX800 and Ratel 2 (save as spares)
- [ ] Install HDZero camera mount
- [ ] Mount HDZero camera
- [ ] Install HDZero VTX module
- [ ] Wire camera to VTX
- [ ] Wire VTX to FC (check HDZero protocol requirements)
- [ ] Wire VTX to power (VBAT/GND)
- [ ] Route and secure VTX antenna
- [ ] Configure HDZero protocol in Betaflight
- [ ] Configure OSD layout
- [ ] Set up HDZero Goggle 2 with Echo antenna kit
- [ ] Test video feed with HDZero Goggle 2
- [ ] Test HD recording functionality
- [ ] Verify VTX power level and channel
- [ ] Update RD-59_AsBuilt_Parts_List.md

**Decision Point**: Choose between MOD-002B (Walksnail) or MOD-002C (HDZero) based on analog testing and system evaluation. Only one digital system will be installed.

---

### PHASE 2: OPTIONAL ENHANCEMENTS

**Objective**: Add enhancements after aircraft is flying and baseline performance is established

**Installation Sequence**: Complete Phase 1 (MOD-001 + MOD-002) and test flights first, then proceed with these optional enhancements.

---

### MOD-003: RGB Arm LED Installation

**Status**: 🟡 **PENDING** - Parts on hand, awaiting installation after Phase 1
**Type**: Enhancement
**Priority**: LOW (aesthetic upgrade - install after aircraft is flying)
**Parts Acquired**: June 4, 2025 (already owned before drone acquisition)

#### Description

Installation of programmable RGB LEDs on motor arms for visibility and aesthetics.

#### Modification Details

| Item | Original Config | Modified Config |
|---|---|---|
| **Arm LEDs** | None | SpeedyBee Programmable 2812 Arm LEDs (4 pcs) |
| **LED Control** | None | FC LED output (programmable) |

#### Rationale

- Improved visibility during flight (orientation and position)
- Aesthetic enhancement
- Low-light/night flying aid
- Already owned these LEDs prior to acquiring RD-59

#### Expected Impact

- Enhanced visual orientation during flight
- Night flying capability
- Weight impact: Minimal (~2-4g total for 4 LEDs)
- Minor power draw from battery

#### Parts On Hand

- [x] SpeedyBee Programmable 2812 Arm LEDs x4 (acquired June 4, 2025)

#### Installation Checklist

**LED Pad Identification** (from BLITZ ATF435 wiring diagram):

- **LED Signal Pad**: Labeled "LED" on FC (WS2812 compatible)
- **Power Options**: 5V or VBAT depending on LED voltage requirements
- **Ground**: GND pad

**Physical Installation**:

- [ ] Mount SpeedyBee 2812 LEDs on motor arms (one per arm)
- [ ] Position LEDs visible from sides/rear for orientation
- [ ] Verify LED power requirements (5V vs VBAT)

**Wiring Connections**:

- [ ] Wire LEDs in series (Data Out from LED1 → Data In to LED2, etc.)
- [ ] Solder first LED Data In wire to LED pad on FC
- [ ] Solder LED power wire to 5V or VBAT pad (check LED specs)
- [ ] Solder LED ground wire to GND pad
- [ ] Secure wiring to arms with heat shrink/tape

**Configuration & Testing**:

- [ ] Enable LED Strip in Betaflight Configuration tab
- [ ] Configure LED count to 4 (one per arm)
- [ ] Configure LED layout in Betaflight LED Strip tab
- [ ] Program LED patterns/colors (orientation indicators)
- [ ] Test LED functionality (power on test)
- [ ] Verify LED patterns during arm/disarm
- [ ] Update RD-59_AsBuilt_Parts_List.md

---

### MOD-004: VIFLY GPS-mate Power Module Installation

**Status**: 🟡 **PENDING** - Parts on hand, awaiting installation after Phase 1
**Type**: Enhancement
**Priority**: MEDIUM (improves GPS performance - install after aircraft is flying)
**Parts Ordered**: July 17, 2025
**Parts Delivered**: July 24, 2025

#### Description

Installation of VIFLY GPS-mate external power module with built-in Finder 2 buzzer to provide clean power to existing iFlight GPS.

#### Modification Details

| Item | Original Config | Modified Config |
|---|---|---|
| **GPS Power** | Powered from FC 5V rail | VIFLY GPS-mate (dedicated power module) |
| **GPS Module** | iFlight GPS (existing) | iFlight GPS (unchanged) |
| **Buzzer** | None or FC buzzer | VIFLY Finder 2 buzzer (built into GPS-mate) |

#### Rationale

- **Clean power for GPS**: GPS-mate provides dedicated, filtered power to GPS module
- **Improved GPS performance**: Reduced electrical noise improves satellite acquisition and accuracy
- **Built-in buzzer**: Finder 2 buzzer aids in locating aircraft after crashes
- **Not a replacement**: This powers the existing iFlight GPS, doesn't replace it

#### Expected Impact

- Faster GPS satellite lock
- Improved GPS accuracy and stability
- Lost model finder functionality
- Weight impact: Minor (~5-10g)
- Additional crash recovery aid

#### Parts On Hand

- [x] VIFLY GPS-mate External GPS Power Module w/ Built-In Finder 2 Buzzer (delivered July 24, 2025)

#### Installation Checklist

**GPS Power Identification** (from BLITZ ATF435 wiring diagram):

- **Current GPS Connection**: iFlight GPS connected to SDA/SCL pads (I2C)
- **Current Power**: GPS powered from FC 5V rail
- **GPS-mate Purpose**: Provide clean, filtered power to reduce electrical noise

**Physical Installation**:

- [ ] Identify GPS power wires on existing iFlight GPS (5V and GND)
- [ ] Find suitable mounting location for GPS-mate module
- [ ] Install GPS-mate module (double-sided tape or mounting pad)

**Wiring Connections**:

- [ ] Disconnect GPS 5V wire from FC 5V pad
- [ ] Keep GPS GND connected to FC GND (common ground)
- [ ] Connect GPS-mate input power (+) to VBAT pad on FC
- [ ] Connect GPS-mate input ground (-) to GND pad on FC
- [ ] Connect GPS-mate output power to GPS 5V wire (now powered by GPS-mate)
- [ ] Leave GPS data wires (SDA/SCL) connected to FC (unchanged)

**Finder 2 Buzzer Configuration**:

- [ ] Locate Finder 2 buzzer output on GPS-mate module
- [ ] Connect buzzer wires if external buzzer needed (optional)
- [ ] Configure Finder 2 buzzer settings (refer to VIFLY manual)

**Testing & Verification**:

- [ ] Power on aircraft, verify GPS-mate power LED illuminates
- [ ] Verify GPS still communicates with FC (check Betaflight GPS tab)
- [ ] Test GPS satellite acquisition (compare before/after times)
- [ ] Test Finder 2 buzzer functionality (lost model alarm)
- [ ] Verify GPS accuracy improvement (check HDOP values)
- [ ] Secure all wiring with heat shrink/tape
- [ ] Update RD-59_AsBuilt_Parts_List.md

---

## Completed Modifications

### MOD-001: ELRS Receiver Installation - 🟢 COMPLETED Nov 13, 2025

See MOD-001 section above for full installation details. Receiver installed and wired; awaiting binding and configuration.

---

## Future Considerations

### SpeedyBee F7 50A V3 Combo Stack (Not Yet Planned)

**Status**: 🔵 **ON HAND** - Not an active modification
**Parts Ordered**: July 17, 2025
**Parts Delivered**: July 24, 2025

#### Description

SpeedyBee F7 50A V3 combo stack purchased and on hand, but **not currently planned for installation**. This is a potential future upgrade option once the current BLITZ ATF435/E55S stack has been tested and evaluated.

#### Why On Hand

- Purchased as a "good future stack for the 5-inch"
- Current BLITZ stack performance is unknown (aircraft not yet flown)
- Provides backup option if BLITZ stack proves inadequate
- Can be evaluated after establishing baseline performance

#### Current Status

- BLITZ ATF435 FC + BLITZ E55S ESC remain installed
- SpeedyBee stack stored for potential future use
- **No modification planned until current stack is tested**

#### Next Steps

- Complete MOD-001 through MOD-004 (receiver, video, LEDs, GPS-mate)
- Test fly RD-59 with current BLITZ stack
- Evaluate performance and identify any issues
- Decide if SpeedyBee stack upgrade is needed

**Note**: This will only become an active modification (MOD-005 or later) if operator decides to replace the BLITZ stack after flight testing.

---

## Modification Categories

**Understanding Modification Types**:

- **Initial Installation**: Installing component that was never present
- **Emergency Repair**: Forced modification due to crash damage
- **Upgrade**: Replacing functional component with better alternative
- **Enhancement**: Adding new capability not present before
- **Replacement**: Like-for-like part swap due to wear or failure

---

## Modification Numbering

Modifications are numbered sequentially: MOD-001, MOD-002, MOD-003, etc.

**Status Indicators**:

- 🔴 **PROPOSED**: Modification being considered
- 🟡 **PENDING**: Parts ordered, awaiting installation
- 🔵 **IN PROGRESS**: Installation underway
- 🟢 **COMPLETED**: Modification finished and tested

---

## Related Documents

- **Parts List**: `RD-59_AsBuilt_Parts_List.md`
- **Incident Log**: `RD-59_Incident_Log.md`
- **Timeline**: `RD-59_Build_Timeline.md`
- **Factory Specs**: `reference/Nazgul_DC5_ECO_Factory_Specs.md`

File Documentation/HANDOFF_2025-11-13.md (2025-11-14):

# RD-59 "Nazgul" Session Handoff - November 13, 2025

**From**: Claude (Session ending at ~108k tokens)
**To**: Next Claude Instance
**Date**: November 13, 2025
**Session Summary**: Major installation progress - MOD-001 and MOD-002A completed

---

## Critical Context

**Aircraft Type**: RD-59 "Nazgul" - **CRUISER BUILD** (not freestyle!)

- 10° camera angle for gentle cruising flight
- Focus on flight time and efficiency over performance
- Gentle, relaxed flying style

**Current Status**: ❌ NOT AIRWORTHY

- ✅ Receiver installed (MOD-001 complete)
- ✅ Camera + VTX installed (MOD-002A complete)
- ⏳ **Configuration pending** - Betaflight setup required before flight
- ⏳ **Testing pending** - No bench test yet

---

## What Was Completed Today (November 13, 2025)

### MOD-001: ELRS Receiver Installation ✅ COMPLETE

**Hardware Installed:**

- HappyModel ExpressLRS TCXO EP1 Dual RX
- Mounted in original DJI receiver bracket (hot glued, wrapped in heat shrink)

**Wiring:**

- UART3 used (R3/T3 pads) - NOT UART2 as originally planned
- EP1 RX (blue wire) → FC T3
- EP1 TX (blue wire/yellow ends) → FC R3
- EP1 5V (red wire) → FC 5V
- EP1 GND (red/black ends) → FC GND
- Wire: 24AWG silicone (signals), 24AWG stranded non-silicone (power)
- Twisted pairs for EMI reduction

**Antenna Configuration:**

- Primary: **Horizontal** (parallel to body), rear exit, **17.5mm CF clearance** ✅
- Secondary: **Vertical** (up/down), side behind VTX, **4mm CF clearance** ⚠️ (marginal)
- **90° diversity achieved** ✅

**Status**: Soldering complete, antennas mounted, **Betaflight config pending**

---

### MOD-002A: Analog Video System Installation ✅ COMPLETE

**Camera Mount - Custom TPU V3:**

- Reverse-engineered Nazgul bumper from photos (GIMP → Inkscape → Bambu Slicer)
- Integrated with Printables Ratel 2 protective sleeve
- Built-in 15° compensation wedge for camera angle
- **Net camera angle: ~10° upward** (cruising config)
- Material: Bambu TPU (red), X1C + AMS, 0.16mm HQ, solid 4-wall construction
- Fits perfectly in aluminum DJI housing
- Source: <https://www.printables.com/model/1339078-caddx-ratel-2-crash-protection-sleeve-tpu>

**Hardware Installed:**

- CADDX Ratel 2 camera (red) - mounted in V3 custom bumper
- SpeedyBee TX800 VTX (5V powered, 3.7-5V input range)
- TrueRC CORE 85mm MMCX RHCP antenna (replaces damaged RD-53 antenna)

**Wiring Harness (Camera + VTX → FC):**

- Camera Red → FC 5V
- Camera Black → FC GND
- VTX Red → FC 5V (**NOT VBAT!** TX800 is 3.7-5V only)
- VTX Black → FC GND
- VTX Green (IRC Tramp RX) → FC T1 (UART1 TX)
- Wires: 24AWG, twisted, tinned, soldered, heat-shrunk
- Routed over top of FC (more room than between layers)

**VTX Antenna:**

- TrueRC CORE 85mm MMCX RHCP
- Mounted **45° angle** out rear
- Custom TPU threaded screw mount (repurposed dual antenna hole)

**Status**: Soldering complete, camera/VTX mounted, antenna secured, **Betaflight config pending**

---

## IMMEDIATE NEXT STEPS (Priority Order)

### 1. Betaflight Configuration (USB-powered bench test safe)

**UART Configuration:**

- **UART3**: Enable for Serial RX, set protocol to CRSF (ELRS receiver)
- **UART1**: Enable for VTX, set protocol to IRC Tramp (TX800 control)

**Critical Settings:**

- VTX: Set to **pit mode (25mW)** for USB testing
- Receiver: Not yet bound to transmitter

### 2. USB-Powered Video Bench Test

**Why USB is safe:**

- TX800 is 5V powered (3.7-5V range)
- Pit mode (25mW) draws minimal current
- FC provides 5V from USB
- **ANTENNA MUST BE CONNECTED** ⚠️

**Test checklist:**

- Power via USB only (no LiPo yet)
- Verify video feed in analog goggles
- Check camera angle (~10° upward for cruising)
- Verify OSD displays
- Test VTX control (channel switching via IRC Tramp)
- **DO NOT switch to high power (200/800mW) on USB!**

### 3. ELRS Receiver Binding

- Bind EP1 to transmitter
- Test control inputs (roll/pitch/yaw/throttle)
- Configure failsafe
- Verify RSSI in OSD

### 4. Full Power-Up Test (With LiPo)

**Prerequisites:**

- USB tests successful
- Receiver bound and tested
- Props OFF for initial power-up

**Test:**

- Connect 6S LiPo (GNB 1350mAh)
- Verify all systems operational
- Test VTX at higher power (200/800mW)
- Test motor outputs (props OFF!)

### 5. Pre-Flight Checks

- Install props (Gemfan 51433 Hurricane - grey front, yellow rear)
- Final antenna routing verification
- Full system check
- First hover test (LOS)

---

## Known Issues / Warnings

### Critical Safety Items

1. **TX800 Power**: 3.7-5V ONLY (NOT VBAT 22.2V!) - Would instantly destroy VTX
2. **VTX Antenna**: MUST be connected before powering VTX (even pit mode)
3. **Secondary ELRS antenna**: 4mm CF clearance (marginal - monitor for signal issues)

### Configuration Notes

1. **UART assignments different from plan**:
   - ELRS on UART3 (not UART2 as recommended)
   - VTX on UART1 (as planned)

2. **Camera angle verification needed**:
   - Design target: ~10° upward
   - Needs visual confirmation in goggles
   - Can add friction shim if angle needs adjustment

3. **Antenna routing adapted**:
   - ELRS primary horizontal (not vertical as originally planned)
   - Still achieves 90° diversity with vertical secondary

---

## Files Updated This Session

**Completed:**

- `/Documentation/RD-59_Modifications_Log.md` - MOD-001 marked complete with installation details

**Needs Update** (for next session):

- `/Documentation/RD-59_Modifications_Log.md` - MOD-002A completion details
- `/Documentation/RD-59_AsBuilt_Parts_List.md` - Mark receiver/video as operational
- `/Documentation/RD-59_Build_Timeline.md` - Add Nov 13 milestones
- `/Documentation/RD-59_Phase1_Installation_Guide.md` - Update with actual config

---

## Photos Pending Documentation

Operator has photos of:

- V3 camera mount installed
- All antenna routing (ELRS + VTX)
- Final stack assembly
- Overall build progress

**Action**: Request photos and add to `/Documentation/reference/build-photos/2025-11-13/`

---

## Technical Specifications Summary

**Flight Controller**: BLITZ ATF435

**UART Allocation:**

- UART1 (R1/T1): VTX control (IRC Tramp)
- UART3 (R3/T3): ELRS receiver (CRSF)
- UART2, 4, 5, 6: Available

**Power Distribution:**

- Camera: 5V rail
- VTX: 5V rail (**NOT VBAT!**)
- ELRS: 5V rail

**Antennas:**

- ELRS Primary: Horizontal, rear, 17.5mm CF clearance
- ELRS Secondary: Vertical, side, 4mm CF clearance
- VTX: TrueRC CORE 85mm RHCP, 45° angle rear

**Camera**: CADDX Ratel 2, ~10° upward angle (cruiser config)

---

## Operator Preferences / Build Philosophy

**SpyD (Franco Nogarin) - Build Approach:**

- Self-sufficient: Designs/prints custom parts (Bambu X1C + AMS)
- Pragmatic: Tests prototypes before iteration (V1→V2→V3 camera mount)
- Resourceful: Photo → GIMP → Inkscape → Slicer workflow (no CAD software)
- Efficient: "Takes longer to loop you in than do it myself"
- Quality-focused: Twisted wire pairs for EMI, proper strain relief

**Documentation Style:**

- Appreciates technical accuracy over hand-holding
- Values engineering rationale ("why" not just "what")
- Expects archivist role (document, don't instruct)

---

## Build Context

**Aircraft History:**

- Purchased July 15, 2025 from Devon "Toasty" Felker ($273.12 CAD)
- Partial build: DJI O4 removed, no receiver
- 121 days from acquisition to first installations (Nov 13)

**Parts Timeline:**

- June 4, 2025: ELRS receiver + LEDs acquired (pre-purchase)
- July 17, 2025: Walksnail/batteries/props ordered
- July 24, 2025: Parts delivered
- Nov 2, 2025: HDZero system ordered ($829.98)
- Nov 13, 2025: **First installations completed!**

**Strategic Goals:**

- Analog first (max flight time 5-7 min)
- Evaluate if digital needed (Walksnail vs HDZero decision pending)
- HDZero test platform for potential fleet-wide transition
- Cruising build (not racing/freestyle)

---

## What to Tell the User

When next Claude instance starts:

"I've reviewed the handoff from the previous session. Excellent progress yesterday (Nov 13)! You completed:

- ✅ MOD-001: ELRS receiver fully installed
- ✅ MOD-002A: Camera/VTX fully installed
- ✅ All wiring soldered and secured
- ✅ All antennas mounted

**Ready for the next phase**: Betaflight configuration and bench testing.

Since the TX800 is 5V powered, we can safely test video over USB (pit mode 25mW) without a LiPo.

Shall we configure Betaflight and do the initial video test?"

---

## Documentation Archive

**This handoff saved to**: `/Documentation/HANDOFF_2025-11-13.md`

**Session stats:**

- Start tokens: ~23k
- End tokens: ~108k
- Session duration: Extended installation session
- Major work: MOD-001 + MOD-002A complete

**Next session should**:

1. Read this handoff first
2. Review `/Documentation/CLAUDE.md` (role/responsibilities)
3. Proceed with Betaflight config
4. Update remaining documentation files

---

## End of Handoff

Next Claude: You're the archivist and SME. Accuracy matters. Document everything. RD-59 deserves a complete record.

Good luck! 🚁

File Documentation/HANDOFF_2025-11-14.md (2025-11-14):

# RD-59 "Nazgul" Session Handoff - November 14, 2025

**From**: Claude (Session ending at ~71k tokens)
**To**: Next Claude Instance
**Date**: November 14, 2025
**Session Summary**: Betaflight configuration and bench testing - TX800 VTX FAILED; strategic decisions made

---

## Critical Context

**Aircraft Type**: RD-59 "Nazgul" - **CRUISER BUILD** (not freestyle, not mapping)
- 10° camera angle for gentle cruising flight
- Focus on flight time and efficiency
- Manual FPV flying (not autonomous)

**Current Status**: ❌ NOT AIRWORTHY
- ✅ Receiver installed (MOD-001 complete - Nov 13)
- ✅ Camera/VTX wiring harness built (Nov 13)
- ✅ Betaflight 4.5.1 configured for analog VTX
- ❌ **TX800 VTX FAILED bench test** (Nov 14)
- ⏳ **Awaiting GEPRC RAD Mini 1W replacement VTX** (order pending)

---

## What Was Completed Today (November 14, 2025)

### Betaflight Configuration ✅ COMPLETE

**Environment:**
- FC: BLITZ ATF435 running Betaflight 4.5.1 (released Jan 16, 2025)
- Software: Betaflight Configurator 10.10.0
- Power: USB only (5V)

**Configuration Steps:**

1. **Initial Connection**:
   - FC detected as IFLIGHT_BLITZ_F435
   - Accelerometer calibration completed
   - Craft name: "Nazgul DC5 ECO" (already set)

2. **Discovered Old DJI O4 Configuration**:
   - UART1 (serial 0) was set to VTX (MSP + Displayport) - DJI digital config
   - UART3 (serial 2) already configured for Serial RX (CRSF) - correct for ELRS ✅

3. **VTX Table Configuration** (via CLI):
   - 5 bands: Boscam A, B, E, Fatshark, Raceband
   - 8 channels per band
   - 4 power levels: 25mW (PIT), 200mW, 400mW, 800mW (MAX)
   - Initial settings: Raceband 1 (5658MHz), Pit mode (25mW)

4. **UART1 Protocol Correction**:
   - Initial attempt: Generic VTX (function 2048) via CLI - WRONG
   - Correct configuration: **VTX (IRC Tramp)** via Ports tab in Configurator
   - Result: "Device ready: True" ✅ (VTX communication established)

5. **Final Configuration**:
   - UART1: IRC Tramp protocol for VTX control
   - UART3: CRSF for ELRS receiver
   - VTX halfduplex: ON
   - VTX low power disarm: UNTIL_FIRST_ARM (safe for benching)

**Result**: Betaflight fully configured and ready for analog VTX ✅

---

### TX800 Bench Test ❌ FAILED

**Test Setup:**
- Power: USB only (5V)
- Goggles: Analog FPV goggles
- Antenna: TrueRC CORE 85mm MMCX RHCP (connected throughout - no RF damage)

**Problems Discovered:**

1. **VTX Ran at Full Power Initially**:
   - Default VTX config had no power limits before our configuration
   - VTX likely running at 800mW on USB before pit mode configured
   - TX800 became **extremely hot** during initial USB connection
   - Heat persisted even after pit mode (25mW) configuration

2. **No Video Output**:
   - VTX communication with FC: ✅ Working (IRC Tramp, Device ready: True)
   - VTX LED status: Red/blue flashing 1 per second (indicates no video input from camera)
   - Goggles: No video signal on Raceband 1 (R1 - 5658MHz)
   - Tested at 200mW on R8: Still no video signal
   - Attempted manual VTX mode button: Behavior inconsistent, LEDs blocked by heatsink

3. **Excessive Heat**:
   - TX800 running dangerously hot even supposedly in pit mode (25mW)
   - Heat excessive even when "doing nothing"
   - LED indicators blocked by heatsink (poor design - cannot clearly see status)
   - VTX temperature abnormal for USB-powered pit mode operation

**Root Cause Analysis**:
- Likely: Camera not providing video signal to VTX (red/blue LED pattern indicates this)
- Possible: Camera power issue (though wired correctly to 5V/GND)
- Possible: Video wire issue (though JST harness verified correct on Nov 13)
- Possible: VTX internal fault (cannot rule out)

**Operator Assessment**:
- TX800 problematic from day 1 (operator never happy with it)
- Poor design (LEDs blocked by heatsink)
- Previous underperformance on 3.5" build (suspected shorting issues)
- Excessive heat concerning (abnormal for pit mode on USB)
- **Trust lost** - combination of heat, no video, and day-1 frustration

**Test Result**: ❌ **BENCH TEST FAILED** - video system not operational

---

## Strategic Decisions Made (November 14, 2025)

### Decision 1: VTX Replacement - GEPRC RAD Mini 1W

**Selected VTX**: GEPRC RAD Mini 1W ($74)

**Rationale**:
- Operator already happy with GEPRC RAD from other builds (proven component)
- Analog VTX maximizes flight time for cruiser role (5-7 min expected)
- IRC Tramp protocol (Betaflight already configured for this - no changes needed)
- Lower cost than digital options
- Allows baseline analog testing as originally planned

**Status**: Order pending (operator will order when ready)

---

### Decision 2: ArduPilot Mapping Rebuild - REJECTED

**Operator researched converting RD-59 to ArduPilot mapping platform**, but decided against it.

**Why Rejected**:
- 5" freestyle frames have severe vibration/jello issues for mapping (high-RPM motors, flexible frame)
- Mapping requires 7" long-range frame with low-KV motors (1200-1400KV vs 1800KV)
- Proper mapping platform needs different design from ground up
- Camera requirements for mapping (12-20MP, down-facing or gimbal) add significant weight/complexity
- DJI Mini 4 Pro (operator owns) is NOT suitable for mapping (proprietary ecosystem, no Mission Planner integration)

**Strategic Decision**:
- **RD-59 remains manual FPV cruiser** on Nazgul frame (as originally planned)
- **Professional mapping platform will be separate future project** (7" frame, ArduPilot, proper camera)

---

### Decision 3: Fleet Strategy Clarified

**RD-59 Role in Fleet**:
- Manual FPV cruiser (10° camera angle, long flight time)
- Analog video system (GEPRC RAD)
- 5-7 min flight time target
- Gentle, relaxed flying style

**Other Fleet Aircraft**:
- **RD-53**: Manual FPV (short-range fun)
- **RD-54 "Zorro"**: Manual FPV (Walksnail Avatar, will get HDZero when it arrives)
- **RD-55 "Flylens75"**: Manual FPV (Walksnail Avatar)
- **RD-59 "Nazgul"**: Manual FPV cruiser (analog, long flight time)
- **Future mapping drone**: Separate build (7" frame, ArduPilot, dedicated platform)

**HDZero System** ($830, ordered Nov 2, in transit):
- Goggle 2 (red) with Echo Antenna Kit
- Freestyle V2 1W VTX Kit
- **Allocated to RD-54** for performance flying (not RD-59)

---

## Current Hardware Status

### Installed and Working:

**MOD-001: ELRS Receiver** ✅ COMPLETE (Nov 13)
- HappyModel ExpressLRS TCXO EP1 Dual RX
- Mounted in original DJI receiver bracket
- UART3 (R3/T3 pads)
- Wiring: Twisted pairs, 24AWG, soldered, heat-shrunk
- Antenna configuration:
  - Primary: Horizontal (parallel to body), rear exit, 17.5mm CF clearance ✅
  - Secondary: Vertical (up/down), side behind VTX, 4mm CF clearance ⚠️ (marginal)
  - 90° diversity achieved ✅
- **Status**: Hardware complete, Betaflight configured, **binding deferred to next session**

**Camera Mount** ✅ COMPLETE (Nov 13)
- Custom TPU V3 (reverse-engineered Nazgul bumper)
- Integrated Printables Ratel 2 protective sleeve
- Built-in 15° compensation wedge
- Net camera angle: ~10° upward (cruising config)
- Material: Bambu TPU (red), X1C + AMS
- Fits perfectly in aluminum DJI housing

**Camera** ✅ COMPLETE (Nov 13)
- CADDX Ratel 2 (red)
- Mounted in V3 custom bumper
- Wired to harness: Red (5V), Black (GND), Yellow (Video)

**Wiring Harness** ✅ COMPLETE (Nov 13)
- Camera Red → FC 5V
- Camera Black → FC GND
- VTX Red → FC 5V
- VTX Black → FC GND
- VTX Green (IRC Tramp control) → FC T1 (UART1 TX)
- Camera Yellow (video) → VTX Video Input
- All wires: 24AWG, twisted, tinned, soldered, heat-shrunk
- Routed over top of FC

**Betaflight Configuration** ✅ COMPLETE (Nov 14)
- UART3: Serial RX (CRSF) for ELRS receiver
- UART1: VTX (IRC Tramp) for analog VTX control
- VTX table: 5 bands, 8 channels, 4 power levels
- VTX settings: Pit mode enabled, low power disarm configured
- Ready for analog VTX (GEPRC RAD)

---

### Failed Components:

**SpeedyBee TX800 VTX** ❌ FAILED (Nov 14)
- Status: Installed but non-functional
- Communication: Working (IRC Tramp, Device ready: True)
- Video output: None (no signal in goggles)
- Heat: Excessive (abnormal for pit mode)
- LED: Red/blue flashing (indicates no video input from camera)
- **Action**: Remove and replace with GEPRC RAD Mini 1W
- **Disposal**: Keep as spare/test part (might be useful for troubleshooting)

**TrueRC CORE 85mm MMCX RHCP Antenna** ✅ WORKING (will transfer to GEPRC RAD)
- Mounted 45° angle out rear
- Custom TPU threaded screw mount
- No damage during TX800 testing

---

## IMMEDIATE NEXT STEPS (Priority Order)

### 1. Order GEPRC RAD Mini 1W VTX

**Pending**: Operator will order when ready ($74)

**Specs to Verify When Ordering**:
- GEPRC RAD Mini 1W (not the 400mW version)
- 25-800mW power range
- IRC Tramp protocol support
- 5V or VBAT power input (verify compatibility)
- MMCX antenna connector (to reuse TrueRC CORE antenna)

---

### 2. Remove Failed TX800 and Install GEPRC RAD

**When GEPRC RAD Arrives**:

1. **Power off and disconnect everything**

2. **Remove TX800**:
   - Disconnect VTX from harness (JST connector)
   - Remove VTX antenna (MMCX - careful not to damage)
   - Unmount TX800 from frame
   - Set aside as spare/test part

3. **Install GEPRC RAD**:
   - Mount GEPRC RAD in same location (or better location if available)
   - Connect TrueRC CORE 85mm MMCX antenna to GEPRC RAD
   - Connect GEPRC RAD to existing wiring harness:
     - Red (5V) → already wired to FC 5V
     - Black (GND) → already wired to FC GND
     - Green/Yellow (IRC Tramp control) → already wired to FC T1 (UART1 TX)
     - Video In → already wired to camera Yellow wire
   - Verify all connections secure
   - **CRITICAL**: Antenna must be connected before powering VTX

4. **Verify Power Requirements**:
   - Check if GEPRC RAD is 5V or VBAT powered
   - Current harness wired to 5V (TX800 was 5V only)
   - If GEPRC RAD needs VBAT, rewire power to VBAT pad

---

### 3. USB-Powered Video Bench Test

**Prerequisites**:
- GEPRC RAD installed
- Antenna connected (**CRITICAL** - never power VTX without antenna)
- Harness verified

**Test Procedure**:
1. Connect FC to USB only (no LiPo)
2. Power on analog goggles
3. Set goggles to Raceband 1 (R1 - 5658MHz) or band/channel configured in Betaflight
4. Verify video feed appears in goggles
5. Check camera angle (~10° upward for cruising)
6. Verify OSD displays (battery voltage, craft name, etc.)
7. Test VTX control via Betaflight VTX tab (channel switching)
8. **Keep in pit mode (25mW) for USB testing** - do NOT switch to high power on USB

**Expected Result**:
- Video signal in goggles ✅
- OSD visible ✅
- Camera angle correct (~10° upward) ✅
- VTX communication working (Device ready: True) ✅

**If Successful**: Proceed to ELRS binding

**If Failed**: Troubleshoot camera/video signal (but GEPRC RAD is proven component, should work)

---

### 4. ELRS Receiver Binding

**Prerequisites**:
- USB or LiPo power to FC
- Transmitter: RadioMaster Boxer with Ranger Micro ELRS TX module
- Binding phrase must match between TX and RX

**Binding Procedure**:

1. **Put Receiver in Bind Mode** (choose one method):
   - **Method A**: Use Betaflight CLI: `bind_rx` command, then reboot
   - **Method B**: Short bind pads on EP1 receiver before powering on
   - **Method C**: Use Betaflight Receiver tab (if available)

2. **Put Transmitter in Bind Mode**:
   - Access ELRS Lua script on Boxer
   - Select "Bind" option
   - Transmitter starts broadcasting bind packets

3. **Wait for Bind**:
   - EP1 receiver should bind automatically (matching binding phrase)
   - LED on receiver changes pattern (rapid flash → solid/slow flash)
   - Betaflight Receiver tab shows RSSI and link quality

4. **Test Control Inputs**:
   - Move sticks on Boxer → Should see response in Betaflight Receiver tab
   - Roll/pitch/yaw/throttle all responding
   - Flight mode switches working
   - RSSI displaying correctly

5. **Configure Failsafe**:
   - Set failsafe mode in Betaflight (Drop, Land, or RTH)
   - Test failsafe: Power off transmitter → FC should enter failsafe mode

**Expected Result**: Full RC control via ELRS ✅

---

### 5. LiPo-Powered Full System Test

**Prerequisites**:
- Video system working (USB test passed)
- ELRS receiver bound and tested
- **Props OFF** (critical for bench test)

**Test Procedure**:

1. **Connect 6S LiPo** (GNB 1350mAh):
   - Verify polarity correct
   - Connect XT60 connector
   - **Props must be OFF**

2. **Power-On Checks**:
   - FC boots normally
   - Video feed in goggles (analog)
   - ELRS receiver connected (RSSI displayed)
   - OSD shows battery voltage (~25.2V for full 6S)

3. **Test VTX at Higher Power**:
   - Switch VTX to 200mW or 400mW via OSD
   - Verify VTX handles power (not overheating)
   - Verify video quality stable
   - Return to pit mode when done

4. **Test Motor Outputs** (props OFF!):
   - Betaflight Motors tab
   - Slowly increase motor sliders (one at a time)
   - Verify all 4 motors spin correctly
   - No strange noises or vibrations
   - Return sliders to zero

5. **Arm Test** (props OFF!):
   - Arm aircraft via transmitter
   - Verify arming successful
   - Check OSD flight timer starts
   - Disarm aircraft

**Expected Result**: All systems operational, ready for props and first flight ✅

---

### 6. Pre-Flight Final Checks

**Before Installing Props**:

1. **Antenna Routing Verification**:
   - ELRS primary antenna: 17.5mm CF clearance ✅
   - ELRS secondary antenna: 4mm CF clearance ⚠️ (marginal - monitor for signal issues)
   - VTX antenna: Clear of props, 45° angle rear ✅
   - No antennas touching carbon fiber

2. **Wiring Inspection**:
   - All solder joints secure
   - No wires in prop path
   - Heat shrink intact
   - JST connectors secure

3. **Install Props**:
   - Gemfan 51433 Hurricane (grey front, yellow rear - if available)
   - Or Nazgul F5 props (included with frame)
   - Verify correct rotation (CW vs CCW)
   - Tighten prop nuts securely

4. **Final System Check**:
   - Battery secure
   - All components mounted firmly
   - Camera angle verified (~10° upward)
   - Video feed clear
   - RC control responsive

**Ready for First Flight** ✈️

---

## Known Issues / Warnings

### Critical Safety Items

1. **TX800 Failed Component**:
   - Do not attempt to reuse TX800 on RD-59
   - Excessive heat indicates internal fault
   - No video output despite communication working
   - Keep as spare/test part only

2. **ELRS Secondary Antenna Clearance**:
   - 4mm CF clearance (marginal - under 5mm spec)
   - Monitor for signal issues during flight
   - May need adjustment if range/penetration poor

3. **VTX Antenna MUST Be Connected**:
   - Never power VTX without antenna (even pit mode)
   - Can destroy VTX instantly

4. **10° Camera Angle Verification Needed**:
   - Design target: ~10° upward (cruiser config)
   - Needs visual confirmation in goggles during flight
   - Can add friction shim if angle adjustment needed

---

### Configuration Notes

1. **UART Assignments**:
   - UART1 (R1/T1): VTX control (IRC Tramp)
   - UART3 (R3/T3): ELRS receiver (CRSF)
   - UART2, 4, 5, 6: Available for future use

2. **Power Distribution**:
   - Camera: 5V rail
   - VTX: 5V rail (TX800 was 5V only - verify GEPRC RAD power requirement)
   - ELRS: 5V rail

3. **Betaflight Version**:
   - 4.5.1 (released Jan 16, 2025)
   - Latest stable version
   - No need to update

---

## Files Updated This Session

**Completed**:
- `/Documentation/RD-59_Modifications_Log.md` - Updated with:
  - MOD-002A bench test results (Nov 14)
  - TX800 failure documentation
  - VTX replacement decision (GEPRC RAD)
  - ArduPilot mapping evaluation (rejected)
  - Strategic fleet context

**Needs Update** (for next session):
- `/Documentation/RD-59_Modifications_Log.md` - Update when GEPRC RAD installed:
  - Mark MOD-002A complete
  - Installation date
  - Bench test results (video working)
  - Flight test results (when first flight happens)
- `/Documentation/RD-59_AsBuilt_Parts_List.md` - Update:
  - Remove TX800, add GEPRC RAD
  - Mark video system operational
  - Mark receiver operational (after binding)
- `/Documentation/RD-59_Build_Timeline.md` - Add:
  - Nov 14: Bench test failed, GEPRC RAD ordered
  - Installation date (when parts arrive)
  - First flight date (when it happens)

---

## Technical Specifications Summary

**Flight Controller**: BLITZ ATF435 (iFlight)
- Firmware: Betaflight 4.5.1
- Processor: AT32F435G
- Unique ID: 0x20bd54464c5c000d409722

**UART Allocation**:
- UART1 (R1/T1): VTX control (IRC Tramp)
- UART3 (R3/T3): ELRS receiver (CRSF)
- UART2, 4, 5, 6: Available

**Power Distribution**:
- Camera: 5V rail
- VTX: 5V rail (verify GEPRC RAD requirement)
- ELRS: 5V rail

**Antennas**:
- ELRS Primary: Horizontal, rear, 17.5mm CF clearance
- ELRS Secondary: Vertical, side, 4mm CF clearance ⚠️
- VTX: TrueRC CORE 85mm MMCX RHCP, 45° angle rear

**Camera**: CADDX Ratel 2, ~10° upward angle (cruiser config)

**VTX** (pending replacement):
- Current: SpeedyBee TX800 (failed)
- Replacement: GEPRC RAD Mini 1W (order pending)
- Protocol: IRC Tramp
- Power range: 25-800mW (pit mode to max)

---

## Operator Preferences / Build Philosophy

**SpyD (Franco Nogarin) - Build Approach**:
- Self-sufficient: Designs/prints custom parts (Bambu X1C + AMS)
- Pragmatic: Tests components before committing (TX800 failure validated concerns)
- Resourceful: Photo → GIMP → Inkscape → Slicer workflow (no CAD software)
- Quality-focused: Twisted wire pairs for EMI, proper strain relief
- Strategic thinker: Evaluated ArduPilot mapping thoroughly before rejecting

**Documentation Style**:
- Appreciates technical accuracy over hand-holding
- Values engineering rationale ("why" not just "what")
- Expects archivist role (document, don't instruct unless asked)
- Calls out incorrect assumptions (DJI Mini 4 Pro not suitable for mapping)

**Decision-Making**:
- Research-driven: Investigated 5" frame jello issues independently
- Proven components: Prefers GEPRC RAD (already happy with it) over unknown
- Fleet strategy: Clear separation of roles (RD-59 cruiser, mapping platform separate)

---

## Strategic Context

**RD-59 Mission** (Finalized Nov 14):
- Manual FPV cruiser (10° camera angle, gentle flying)
- Analog video system (GEPRC RAD - maximizes flight time)
- Target flight time: 5-7 minutes
- NOT a mapping platform (5" frame unsuitable)
- NOT an aggressive freestyle drone (cruiser philosophy)

**Fleet Context**:
- **RD-53**: Manual FPV (short-range fun)
- **RD-54 "Zorro"**: Manual FPV (Walksnail → HDZero when arrives)
- **RD-55 "Flylens75"**: Manual FPV (Walksnail)
- **RD-59 "Nazgul"**: Manual FPV cruiser (analog, long flight time)
- **Future mapping drone**: Separate build (7" frame, ArduPilot, 12-20MP camera)

**HDZero System** (in transit):
- $830 investment (Goggle 2 + Freestyle V2 kit)
- Ordered Nov 2, 2025
- Expected delivery: Mid-November (any day now)
- **Allocated to RD-54** for performance flying
- NOT for RD-59 (analog better for cruiser role)

**Mapping Platform** (future project):
- 7" long-range frame required
- Low-KV motors (1200-1400KV)
- ArduPilot firmware (not Betaflight)
- 12-20MP camera (down-facing or gimbal-mounted)
- Professional WebODM workflow integration
- Separate from RD-59 entirely

---

## Build Timeline Context

**Aircraft History**:
- July 15, 2025: Purchased from Devon "Toasty" Felker ($273.12 CAD)
- Partial build: DJI O4 removed, no receiver
- Condition: All flight electronics operational (FC, ESC, motors, GPS)

**Parts Acquisition**:
- June 4, 2025: ELRS receiver + LEDs (pre-purchase)
- July 17, 2025: Walksnail/batteries/props ordered
- July 24, 2025: Parts delivered
- Nov 2, 2025: HDZero system ordered ($829.98)
- Nov 13, 2025: First installations (ELRS + camera/VTX)
- Nov 14, 2025: Bench test (TX800 failed)
- **Pending**: GEPRC RAD order (~$74)

**Time from Acquisition to First Installations**: 121 days (July 15 → Nov 13)

**Time Since Installation**: 1 day (Nov 13 → Nov 14 bench test)

---

## What to Tell the User

When next Claude instance starts:

"I've reviewed the handoff from November 14th. You made excellent progress yesterday:

✅ **Betaflight fully configured**:
- UART1: IRC Tramp for VTX control
- UART3: CRSF for ELRS receiver
- VTX table configured (5 bands, 8 channels, 4 power levels)
- Ready for analog VTX

❌ **TX800 bench test failed**:
- VTX communication working (Device ready: True)
- No video output (camera not sending signal to VTX)
- Excessive heat (abnormal for pit mode)
- Decision made: Replace with GEPRC RAD Mini 1W ($74)

✅ **Strategic decisions finalized**:
- RD-59 remains manual FPV cruiser (not ArduPilot mapping platform)
- 5" frame unsuitable for mapping (vibration/jello issues)
- Professional mapping platform will be separate future build (7" frame)
- HDZero system (in transit) allocated to RD-54

**Current Status**:
- RD-59 reassembled as-is (TX800 still installed but non-functional)
- Awaiting GEPRC RAD Mini 1W order and delivery
- Ready to proceed when new VTX arrives

**Next Steps** (when GEPRC RAD arrives):
1. Remove TX800
2. Install GEPRC RAD (reuse existing camera and harness)
3. Bench test video system
4. Bind ELRS receiver
5. LiPo-powered full system test (props OFF)
6. First flight!

Have you ordered the GEPRC RAD yet? What's the status?"

---

## Documentation Archive

**This handoff saved to**: `/Documentation/HANDOFF_2025-11-14.md`

**Session stats**:
- Start tokens: ~23k (read handoff from Nov 13)
- End tokens: ~71k
- Session duration: Betaflight configuration + bench test + strategic planning
- Major work: TX800 failure diagnosis, VTX replacement decision, ArduPilot evaluation

**Next session should**:
1. Read this handoff first
2. Check if GEPRC RAD has been ordered/delivered
3. Proceed with installation when parts arrive
4. Update documentation files when MOD-002A complete

---

## End of Handoff

Next Claude: You're the archivist and SME. The TX800 failure was frustrating but led to good strategic clarity. RD-59 knows what it wants to be: a gentle FPV cruiser with long flight time. Document the GEPRC RAD installation thoroughly when it happens, and get this bird in the air!

Good luck! 🚁

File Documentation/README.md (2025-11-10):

# RD-59 "Nazgul" Documentation Index

**Drone Designator**: RD-59
**Code Name**: Nazgul
**Operator**: SpyD (Franco Nogarin)
**Platform**: Nazgul DC5 ECO V1.1 - 5" Freestyle Quadcopter

---

## 🚨 Current Status (as of November 10, 2025)

| Status | Value |
|---|---|
| **Airworthiness** | ❌ NOT AIRWORTHY |
| **Flight Status** | Not yet flown by current operator |
| **Acquisition Date** | July 15, 2025 |
| **Days Since Acquisition** | 118 days |
| **Days Parts On Hand** | 109 days (since July 24, 2025) |
| **Test Flights** | 0 |
| **Total Incidents** | 0 |
| **Total Modifications** | 0 completed, 5 pending (MOD-001, 002A, 002B, 003, 004) |

**Installation Plan**: Install RX + Analog VTX → Get it flying → Evaluate → Upgrade if needed

**Phase 1 - Critical** (on hand, ready to install - Analog for max flight time):
- ✓ HappyModel ELRS EP1 Dual RX (MOD-001)
- ✓ SpeedyBee TX800 + CADDX Ratel 2 (MOD-002A - Analog, 5-7 min flight time)

**Phase 1B - Optional Upgrade** (if analog insufficient):
- ✓ Walksnail Avatar HD Moonlight (MOD-002B - Digital, 3-5 min flight time)

**Phase 2 - Optional** (install after test flights):
- ✓ SpeedyBee RGB LEDs (MOD-003)
- ✓ VIFLY GPS-mate w/ Finder 2 (MOD-004)

---

## 📋 Quick Reference

### As-Purchased Configuration (July 15, 2025)

| Component | Status | Notes |
|---|---|---|
| **Frame** | ✓ Operational | Nazgul DC5 240mm DeadCat |
| **Flight Controller** | ✓ Operational | BLITZ ATF435 (untested) |
| **ESC** | ✓ Operational | BLITZ E55S 4-in-1 60A (untested) |
| **Motors** | ✓ Operational | XING-E Pro 2207 1800KV (x4, untested) |
| **GPS** | ✓ Operational | iFlight GPS |
| **Battery Connector** | ✓ Operational | XT60 with anti-spark |
| **Props** | ✓ Available | Nazgul F5 (5-inch) |
| **Receiver** | ❌ NOT INSTALLED | Never included, needs installation |
| **Video System** | ❌ REMOVED | DJI O4 stripped by previous owner |

### Key Differences from Factory Spec

| Component | Factory Spec | As-Purchased | Impact |
|---|---|---|---|
| **Video System** | DJI O4 Air Unit Pro (4K) | REMOVED | No FPV capability |
| **Receiver** | Not included (sold separately) | Not included | No control capability |
| **Weight** | ~450g dry | ~420g dry (lighter without video) | Less weight |

---

## 📚 Primary Documentation

### Core Documents

1. **[RD-59_AsBuilt_Parts_List.md](./RD-59_AsBuilt_Parts_List.md)**
   - **Purpose**: Single source of truth for current configuration
   - **Use When**: Checking component specs, verifying configuration, planning repairs/upgrades
   - **Last Updated**: 2025-11-10
   - **Key Sections**: Operational components, missing components, pending installations

2. **[RD-59_Incident_Log.md](./RD-59_Incident_Log.md)**
   - **Purpose**: Comprehensive crash reports and damage tracking
   - **Use When**: After any crash, incident, or damage
   - **Incidents Recorded**: 0 (not yet flown)
   - **Key Sections**: Incident reports, damage assessments, repair tracking

3. **[RD-59_Modifications_Log.md](./RD-59_Modifications_Log.md)**
   - **Purpose**: Track all engineering changes and upgrades
   - **Use When**: Planning or completing any modification
   - **Modifications Recorded**: 0 completed, 2 pending (MOD-001: Receiver, MOD-002: Video System)
   - **Key Sections**: Planned modifications, completed modifications, rationale

4. **[RD-59_Build_Timeline.md](./RD-59_Build_Timeline.md)**
   - **Purpose**: Chronological project history and future planning
   - **Use When**: Tracking milestones, planning future work, reviewing history
   - **Project Duration**: 118 days since acquisition (July 15 - Nov 10, 2025)
   - **Key Sections**: Acquisition history, phases, milestones, lessons learned

---

## 📖 Reference Materials

### Factory Documentation

1. **[reference/Nazgul_DC5_ECO_Factory_Specs.md](./reference/Nazgul_DC5_ECO_Factory_Specs.md)**
   - **Purpose**: Original factory specifications from iFlight
   - **Use When**: Comparing to original spec, understanding design intent, verifying compatibility
   - **Key Information**: Complete factory specs, performance data, original components

---

## 🔗 External Resources

### Visual Documentation

- **Google Photos Album**: [RD-59 Photo Gallery](https://photos.google.com/album/AF1QipMQ81SgmNKcywQYFzFxxncO6l4DfiegxZddzp05)
  - Comprehensive photo documentation
  - Build process and assembly
  - Component details
  - Acquisition photos (July 14-15, 2025)

- **Local Photo Directory**: `/Users/franconogarin/localcode/spyd.com/public/drone-lab/drones/RD-59/googlePhotos/`
  - Local copies of acquisition photos
  - July 14-15, 2025 timestamps

---

## 🎯 Common Tasks

### Finding Information

**"What components are currently installed?"**
→ See [RD-59_AsBuilt_Parts_List.md](./RD-59_AsBuilt_Parts_List.md)

**"What parts do I need to buy?"**
→ See "Missing Components" section in [RD-59_AsBuilt_Parts_List.md](./RD-59_AsBuilt_Parts_List.md)
→ See pending modifications in [RD-59_Modifications_Log.md](./RD-59_Modifications_Log.md)

**"Has this aircraft crashed?"**
→ See [RD-59_Incident_Log.md](./RD-59_Incident_Log.md) (currently 0 incidents)

**"What modifications have been made?"**
→ See [RD-59_Modifications_Log.md](./RD-59_Modifications_Log.md) (currently 0 completed, 2 pending)

**"When was this aircraft acquired?"**
→ See [RD-59_Build_Timeline.md](./RD-59_Build_Timeline.md) (July 15, 2025)

**"What are the original factory specs?"**
→ See [reference/Nazgul_DC5_ECO_Factory_Specs.md](./reference/Nazgul_DC5_ECO_Factory_Specs.md)

---

## 📝 Documentation Standards

### When to Update Documents

**After Purchasing Parts**:
1. Update `RD-59_Modifications_Log.md` with order details
2. Change modification status to "PENDING"
3. Update `RD-59_Build_Timeline.md` with milestone

**After Installing Parts**:
1. Update `RD-59_AsBuilt_Parts_List.md` with new configuration
2. Update `RD-59_Modifications_Log.md` to "COMPLETED"
3. Update `RD-59_Build_Timeline.md` with completion date
4. Update this README with new status

**After a Crash**:
1. Create new incident report in `RD-59_Incident_Log.md`
2. Document all damage in assessment table
3. Update incident counter
4. Link to any modifications required for repair

**After Test Flights**:
1. Update `RD-59_Build_Timeline.md` with flight milestone
2. Add performance notes to `RD-59_AsBuilt_Parts_List.md`
3. Document any issues discovered

---

## 🚀 Next Steps

**To make RD-59 airworthy**:

1. **Select Receiver** (MOD-001)
   - Research ELRS receiver options
   - Purchase receiver system
   - See: [RD-59_Modifications_Log.md](./RD-59_Modifications_Log.md#mod-001)

2. **Select Video System** (MOD-002)
   - Decide: Analog vs Digital
   - Research options in chosen category
   - Purchase video system
   - See: [RD-59_Modifications_Log.md](./RD-59_Modifications_Log.md#mod-002)

3. **Installation**
   - Install receiver (MOD-001)
   - Install video system (MOD-002)
   - Configure in Betaflight/INAV
   - Bench test all systems

4. **Test Flights**
   - Pre-flight safety checks
   - First hover test
   - First FPV flight
   - Establish baseline performance

---

## ℹ️ Important Notes

**Source of Truth**:
- This repository is the authoritative source for RD-59 technical specifications
- All specs come from operator or verified factory documentation
- Do not trust external AI analysis or visual component identification

**Acquisition Context**:
- Aircraft purchased as partial build from Devon "Toasty" Felker
- DJI O4 video system was removed by previous owner before sale
- No receiver was ever installed (not included in factory package)
- All flight electronics are untested by current operator

**Pre-Acquisition History**:
- Previous owner: Devon "Toasty" Felker (Hay River)
- Flight history by previous owner: Unknown
- Any incidents by previous owner: Unknown
- Original factory build: iFlight

---

## 📧 Repository Information

**Repository**: RD59_Nazgul
**Location**: `/Users/franconogarin/localcode/RD59_Nazgul`
**Documentation**: `/Users/franconogarin/localcode/RD59_Nazgul/Documentation`
**Guidelines**: See `../CLAUDE.md` for documentation standards and assistant guidelines

---

**Last Updated**: November 10, 2025
**Maintained by**: SpyD (Franco Nogarin) with Claude Code

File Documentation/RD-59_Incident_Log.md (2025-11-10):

# RD-59 "Nazgul" Incident Log

**Drone Designator**: RD-59
**Code Name**: Nazgul
**Operator**: SpyD (Franco Nogarin)
**Last Updated**: 2025-11-10

---

## Incident Summary

| Total Incidents | Last Incident Date | Aircraft Status |
|---|---|---|
| **0** | N/A | Not yet flown by current operator |

---

## Incident Reports

**No incidents recorded.**

RD-59 has not yet been flown by the current operator (SpyD) since acquisition on July 15, 2025. Aircraft is awaiting installation of receiver and video system before first test flight.

---

## Incident Report Template

When documenting incidents, use the following format:

### Incident #XXX - [Brief Description]

**Date**: YYYY-MM-DD
**Time**: HH:MM (local time)
**Location**: [Specific location]
**Flight Time Before Incident**: [minutes/hours]
**Operator**: SpyD

#### Environmental Conditions
- **Weather**: [conditions]
- **Wind**: [speed and gusts]
- **Temperature**: [°C]
- **Visibility**: [conditions]
- **Other Aircraft/Pilots**: [who else was flying]

#### Incident Description
[Detailed description of what happened]

#### Damage Assessment

| Component | Status | Damage Severity | Action Required |
|---|---|---|---|
| Component | Damaged/Destroyed/Operational | Minor/Major/Critical | Repair/Replace/None |

#### Root Cause Analysis
[Analysis of what caused the incident]

#### Repair Actions

| Date | Action | Parts Ordered | Vendor | Cost | Status |
|---|---|---|---|---|---|
| | | | | | |

#### Lessons Learned
- [Key takeaway 1]
- [Key takeaway 2]

#### Follow-up Actions
- [ ] Order replacement parts
- [ ] Complete repairs
- [ ] Test flight post-repair
- [ ] Update parts list

---

## Pre-Acquisition History

**Note**: Any incidents that occurred while the aircraft was owned by Devon "Toasty" Felker are unknown. The aircraft was purchased in a partial state with DJI O4 video system already removed.

If information about pre-acquisition incidents becomes available, it will be documented here for historical reference.

---

## Related Documents

- **Parts List**: `RD-59_AsBuilt_Parts_List.md`
- **Modifications**: `RD-59_Modifications_Log.md`
- **Timeline**: `RD-59_Build_Timeline.md`
- **Factory Specs**: `reference/Nazgul_DC5_ECO_Factory_Specs.md`

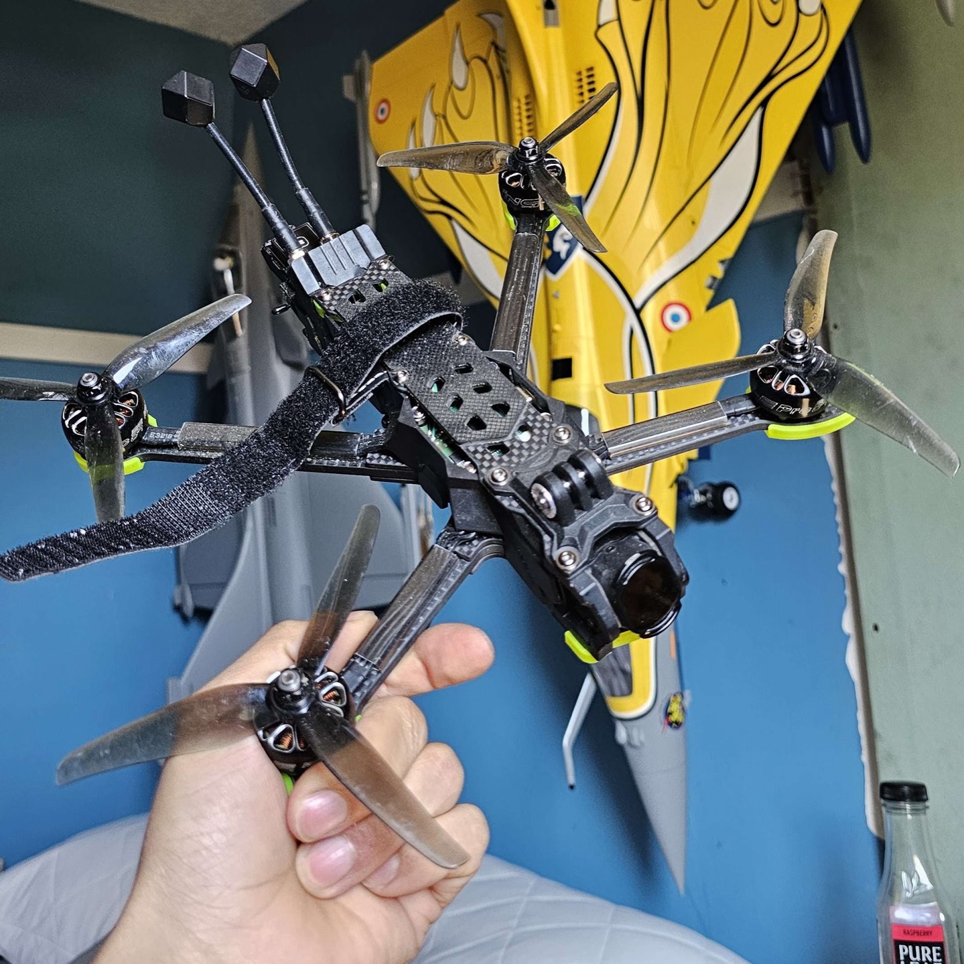
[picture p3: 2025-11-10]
Documentation/reference/Nazgul_Original.jpg

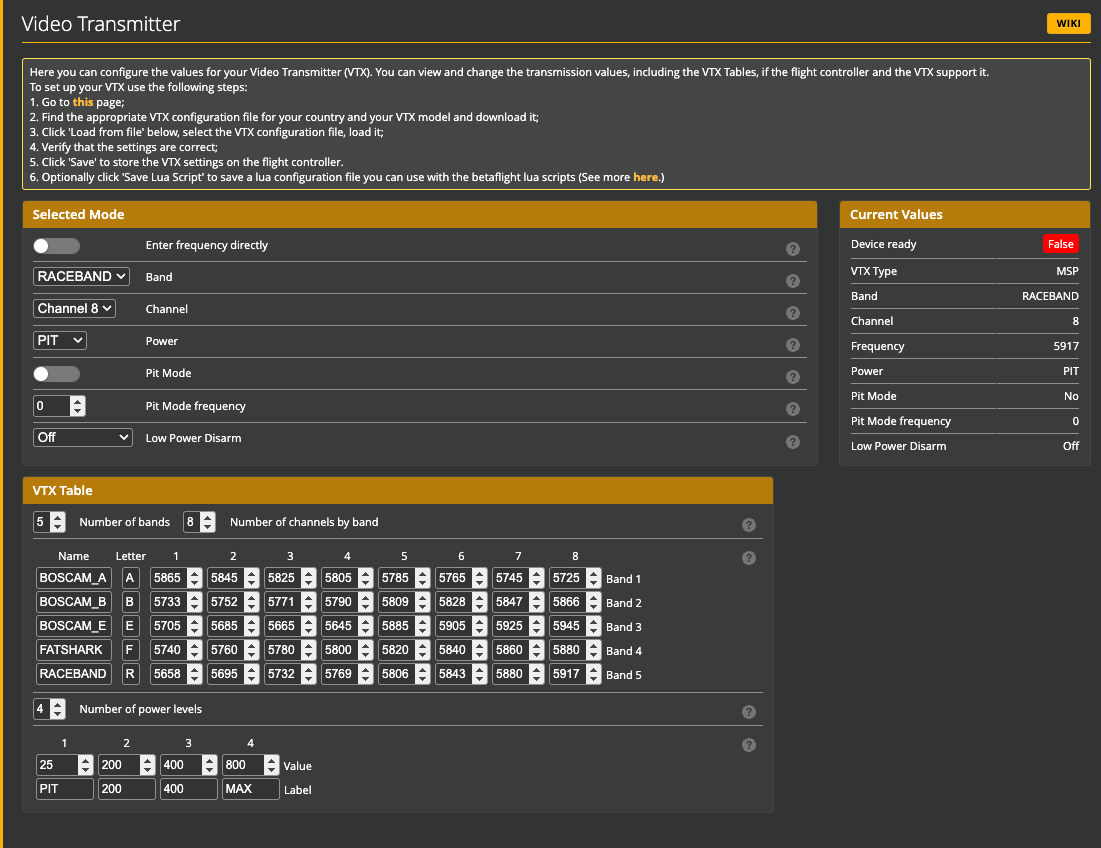
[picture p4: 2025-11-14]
Documentation/reference/screengrabs/Screenshot 2025-11-14 at 9.07.13 AM.png

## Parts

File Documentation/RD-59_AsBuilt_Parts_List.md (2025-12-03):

# RD-59 "Nazgul" As-Built Parts List

**Drone Designator**: RD-59
**Code Name**: Nazgul
**Operator**: SpyD (Franco Nogarin)
**Platform**: Nazgul DC5 ECO V1.1 - 5" Freestyle Quadcopter
**Last Updated**: 2025-12-02

---

## Acquisition History

| Detail | Information |
|---|---|
| **Purchase Date** | July 15, 2025 |
| **Previous Owner** | Devon "Toasty" Felker |
| **Location** | Hay River |
| **Purchase Price** | $273.12 CAD |
| **Original Model** | Nazgul DC5 ECO V1.1 6S HD O4 - ELRS + GPS |
| **Condition at Purchase** | Partial - DJI O4 video system removed, no receiver included |

---

## Current Configuration Status

**Aircraft Status**: ❌ **NOT AIRWORTHY**
**Reason**: Missing receiver and video system
**Test Flights by Current Operator**: None

---

## Component Inventory

### ✓ OPERATIONAL COMPONENTS (As-Purchased July 15, 2025)

#### Airframe

| Component | Specification | Status | Notes |
|---|---|---|---|
| **Frame** | Nazgul DC5 240mm wheelbase | ✓ Operational | DeadCat geometry, carbon fiber |
| **Weight** | ~450g (without battery) | ✓ As spec | Per factory specifications |
| **Dimensions** | 193 × 144 × 34 mm (L×W×H) | ✓ As spec | |

#### Flight Electronics

| Component | Specification | Status | Notes |
|---|---|---|---|
| **Flight Controller** | BLITZ ATF435 | ✓ Operational | Untested by current operator |
| **ESC** | BLITZ E55S 4-in-1 60A | ✓ Operational | Untested by current operator |
| **Motors** | XING-E Pro 2207 1800KV (x4) | ✓ Operational | Untested by current operator |

#### Power System

| Component | Specification | Status | Notes |
|---|---|---|---|
| **Battery Connector** | XT60 | ✓ Operational | Anti-spark technology |
| **Voltage** | 6S (22.2V nominal) | ✓ Compatible | Per original spec |
| **Recommended Battery** | 6S 1480mAh | ✓ Compatible | Factory recommendation |

#### Navigation

| Component | Specification | Status | Notes |
|---|---|---|---|
| **GPS Module** | iFlight GPS | ✓ Operational | Came with aircraft |

#### Propellers

| Component | Specification | Status | Notes |
|---|---|---|---|
| **Factory Props** | Nazgul F5 (5-inch) | ✓ Available | Factory props included |
| **Upgrade Props** | Gemfan 51433 Hurricane Tri-Blade | ✓ Available | Purchased July 17, delivered July 24 |

**Propeller Inventory**:
- Nazgul F5 props (factory, quantity unknown)
- Gemfan 51433 Hurricane (lemon yellow) x4 sets (8 props, 4CW+4CCW) - rear motors
- Gemfan 51433 Hurricane (dark grey) x4 sets (8 props, 4CW+4CCW) - front motors
- **Color scheme rationale**: Dark grey on front motors to stay out of FPV camera view (DeadCat design)

#### Batteries

| Component | Specification | Quantity | Status | Notes |
|---|---|---|---|---|
| **Flight Batteries** | GNB 1350mAh 6S 100C LiPo XT60 | 4 | ✓ Available | Purchased July 17, delivered July 24 |

**Battery Specifications**:
- **Voltage**: 6S (22.2V nominal, 25.2V full charge)
- **Capacity**: 1350mAh
- **Discharge Rate**: 100C continuous
- **Connector**: XT60 (matches aircraft)
- **Weight**: ~165g each (estimated)
- **Expected Flight Time**:
  - Analog (MOD-002A): 5-7 minutes freestyle
  - HDZero (MOD-002C): 4-6 minutes (better than Walksnail due to lighter weight)

**Battery Selection Rationale (1350mAh vs Factory 1480mAh)**:
- **No Action Camera**: Not adding GoPro/action cam weight (~50-130g saved)
- **HDZero Lighter Than O4**: HDZero Freestyle V2 (~45-50g) vs DJI O4 (~70g) = ~20-25g saved
- **Better Power-to-Weight**: Lighter overall build with smaller battery = more aggressive flight characteristics
- **Flight Time Trade-off**: ~30-60 seconds less than 1480mAh, but better performance for freestyle

---

### 🟡 ADDITIONAL COMPONENTS (On Hand)

#### Analog Video Components (MOD-002A - CONFIRMED PATH)

| Component | Specification | Status | Notes |
|---|---|---|---|
| **VTX** | GEPRC RAD Mini 1W (5.8GHz, 25mW-1W) | ✓ ON HAND (arrived Dec 2, 2025) | Replaces failed TX800 |
| **VTX (Failed)** | SpeedyBee TX800 | ❌ FAILED (bench test Nov 14) | No video output, excessive heat - removed |
| **Camera** | CADDX Ratel 2 (red) | ✓ INSTALLED | Analog FPV camera, mounted in custom TPU V3 bumper |

**Purpose**: FPV capability with maximum flight time (5-7 min) - CONFIRMED as RD-59 video system

**Decision (Dec 2, 2025)**: Analog chosen over digital to maximize flight time for cruiser role

#### Digital Video Components - Path 1: Walksnail (MOD-002B - Optional Upgrade)

| Component | Specification | Status | Notes |
|---|---|---|---|
| **Digital System** | Walksnail Avatar HD Moonlight VTX Kit | ✓ ON HAND (delivered July 24, 2025) | Upgrade only if analog insufficient |
| **Goggles** | Goggles X (already owned) | ✓ OWNED | Considerable investment already made |

**Purpose**: HD video quality, onboard recording - upgrade if analog performance unsatisfactory

#### Digital Video Components - Path 2: HDZero (MOD-002C - REALLOCATED)

| Component | Specification | Status | Notes |
|---|---|---|---|
| **Digital System** | HDZero Freestyle V2 Kit | ➡️ REALLOCATED TO RD-54 | Arrived Dec 2, 2025 - allocated to RD-54 Zorro |
| **Goggles** | HDZero Goggle 2 (red) with Echo Antenna Kit | ✓ ARRIVED | $679.99, ordered Nov 2, 2025 |

**Status Update (Dec 2, 2025)**: HDZero VTX reallocated to RD-54 "Zorro" for HDZero evaluation. RD-59 will use analog (MOD-002A) for maximum flight time.

**Fleet Context**:
- **DJI Mini Pro 4**: Complete setup (Motion, Goggles, screen remote) - cinematic/AP platform
- **Walksnail Fleet**: Goggles X + drones with Avatar VTX
  - RD-55 "Flylens75" (Walksnail Avatar VTX installed)
  - RD-59 "Nazgul" (Walksnail Avatar HD Moonlight available as backup)
- **HDZero Fleet**: HDZero Goggle 2 + HDZero VTX
  - RD-54 "Zorro" (HDZero Freestyle V2 - pending install)

#### Arm LEDs (MOD-003)

| Component | Specification | Status | Notes |
|---|---|---|---|
| **RGB LEDs** | SpeedyBee Programmable 2812 Arm LEDs | ✓ ON HAND (acquired June 4, 2025) | 4 pieces for motor arms |

**Purpose**: Visibility and orientation during flight, aesthetic enhancement

#### GPS Power Module (MOD-004)

| Component | Specification | Status | Notes |
|---|---|---|---|
| **GPS Power** | VIFLY GPS-mate w/ Finder 2 Buzzer | ✓ ON HAND (delivered July 24, 2025) | Powers existing iFlight GPS |

**Purpose**: Clean power for GPS, improved performance, built-in lost model buzzer

---

### ❌ MISSING COMPONENTS (Required for Airworthiness)

#### Radio System

| Component | Status | Parts Status | Required Action |
|---|---|---|---|
| **Receiver** | ❌ NOT INSTALLED | ✓ ON HAND (acquired June 4, 2025) | Install HappyModel ELRS EP1 Dual RX |
| **Control Link** | ❌ NONE | Pending installation | ExpressLRS 2.4GHz |

**Parts on Hand (MOD-001)**:
- HappyModel ExpressLRS TCXO EP1 Dual RX
- Dual antennas (included)

#### Video System

| Component | Original Spec | Current Status | Initial Install | Optional Upgrade |
|---|---|---|---|---|
| **Video System** | DJI O4 Air Unit Pro (Digital HD) | ❌ REMOVED by previous owner | **Analog** (MOD-002A) | Digital (MOD-002B) |
| **Camera** | DJI O4 1/1.3" sensor, 155° FOV | ❌ REMOVED | CADDX Ratel 2 (red) | Walksnail Moonlight |
| **VTX** | DJI O4 (5.170-5.850 GHz, 15km) | ❌ REMOVED | SpeedyBee TX800 (5.8GHz, 25-800mW) | Walksnail Avatar VTX |
| **Recording** | DJI O4 4GB onboard | ❌ REMOVED | None (analog) | HD onboard |

**Installation Strategy: Analog First, Then Choose Digital Path**

**MOD-002A: Analog System (Initial Install - Already Owned)**
- SpeedyBee TX800 VTX (5.8GHz, 25-800mW) - liberated from 3.5" build
- CADDX Ratel 2 camera (red) - already owned
- VTX antenna (included with TX800)
- **Flight Time**: 5-7 min (40-50% better than digital)
- **Weight**: +25g (45g lighter than digital)
- **Range**: 2-4km at 800mW

**MOD-002B: Walksnail Digital System (Optional Path 1 - On Hand)**
- Walksnail Avatar HD Moonlight VTX Kit (delivered July 24, 2025)
- Moonlight camera (included in kit)
- VTX module (included in kit)
- Antennas (included in kit)
- Goggles X (already owned)
- **Flight Time**: 3-5 min (40-50% penalty vs analog)
- **Weight**: +70g (45g heavier than analog)
- **Range**: 3-6km (slightly better)
- **Benefits**: HD video quality, onboard HD recording, existing goggles investment

**MOD-002C: HDZero Digital System (Optional Path 2 - In Transit)**
- HDZero Freestyle V2 Kit (ordered Nov 2, expected ~Nov 9-15)
- HDZero camera (included in kit)
- HDZero VTX (included in kit)
- HDZero Goggle 2 (red) with Echo Antenna Kit (ordered Nov 2, $679.99)
- **Flight Time**: 3-5 min (similar to Walksnail)
- **Weight**: Similar to Walksnail (~+45-70g vs analog)
- **Range**: 3-6km (estimated, similar to Walksnail)
- **Benefits**: Lower latency than Walksnail, HD recording, evaluating HDZero ecosystem

**Decision**: Install analog first (MOD-002A), test performance, choose between Walksnail (MOD-002B) or HDZero (MOD-002C) only if needed

**Original Video System Specifications** (for reference):
- **Sensor**: 1/1.3-inch
- **Resolution**: 4K@30fps, 1080p@100fps
- **FOV**: 155° ultra-wide
- **Stabilization**: RockSteady 3.0+
- **Range**: Up to 15 km (FCC)
- **Recording**: 4GB built-in memory

---

## Build Specifications

### Performance Specifications (Factory)

| Specification | Value |
|---|---|
| **Max Speed** | 190 km/h |
| **Max Hover Time** | ~7.5 minutes (with 6S 1480mAh) |
| **Max Flight Altitude** | 7000 m |
| **Wind Resistance** | Up to level 7 |
| **Operating Temperature** | -10 °C to 40 °C |

### Weight Budget

| Category | Weight |
|---|---|
| **Dry Weight** | ~450g ± 5g (without battery) |
| **With 6S 1480mAh Battery** | ~675g ± 5g |
| **Current Configuration** | ~450g (no video system, no receiver) |

---

## Pending Installations

### Phase 1: Critical Airworthiness (Install First)

**Objective**: Install RX + Analog VTX → Get aircraft flying with maximum flight time

| Item | Status | Parts On Hand Since | Notes |
|---|---|---|---|
| **MOD-001: ELRS Receiver** | 🟢 INSTALLED | June 4, 2025 | HappyModel EP1 Dual RX - installed Nov 13, needs binding |
| **MOD-002A: Analog Video System** | ✓ Parts ready | Dec 2, 2025 | GEPRC RAD Mini 1W + Ratel 2 (installed) - CONFIRMED PATH |

**Expected Performance (Phase 1)**:
- Flight time: 5-7 minutes
- Range: 2-4km at 1W
- Weight penalty: +25g (minimal)

### Phase 1B: Optional Digital Upgrade (Walksnail Backup)

**Objective**: Upgrade to Walksnail digital if analog performance unsatisfactory

| Item | Status | Parts On Hand Since | Notes |
|---|---|---|---|
| **MOD-002B: Walksnail Avatar HD** | ✓ Parts on hand | July 24, 2025 | Backup option: Use existing Goggles X investment |
| **MOD-002C: HDZero Freestyle V2** | ➡️ REALLOCATED | Dec 2, 2025 | Allocated to RD-54 Zorro |

**Decision (Dec 2, 2025)**: HDZero VTX allocated to RD-54 "Zorro" for HDZero ecosystem evaluation. RD-59 confirmed for analog (MOD-002A) with Walksnail as backup only.

**If Analog Insufficient - Walksnail (MOD-002B)**:
- Flight time penalty: 3-5 min (vs 5-7 min analog)
- Weight penalty: +45g heavier than analog
- Benefits: HD video, onboard recording, uses Goggles X

### Phase 2: Optional Enhancements (Install After Flying)

**Objective**: Add enhancements after baseline performance established

| Item | Status | Parts On Hand Since | Notes |
|---|---|---|---|
| **MOD-003: RGB Arm LEDs** | ✓ Parts on hand | June 4, 2025 | SpeedyBee 2812 LEDs x4 |
| **MOD-004: GPS-mate Power Module** | ✓ Parts on hand | July 24, 2025 | VIFLY GPS-mate w/ Finder 2 buzzer |

**Installation Plan**: Phase 1 (RX + Analog) → Test flights → Evaluate if digital upgrade needed → Phase 2 enhancements

**Additional Equipment On Hand** (not currently planned for installation):
- **SpeedyBee F7 50A V3 Combo Stack** (delivered July 24, 2025)
  - Future upgrade option for FC/ESC replacement
  - Current BLITZ stack to be evaluated during test flights first
  - See `RD-59_Modifications_Log.md` for details

---

## Known Issues

| Issue | Severity | Impact | Resolution | Status |
|---|---|---|---|---|
| No receiver installed | CRITICAL | Aircraft not controllable | Install HappyModel ELRS EP1 Dual RX (MOD-001) | Parts on hand |
| No video system | CRITICAL | No FPV capability | Install Walksnail Avatar HD (MOD-002) | Parts on hand |
| Not test flown by operator | INFO | Unknown operational baseline | Complete installations, then test flight | Pending MOD-001/002 |

**Status Update**: All critical parts are on hand as of July 24, 2025. Aircraft is ready for installation work to begin.

---

## Modification History

**Completed Modifications**:
- **MOD-001**: ELRS Receiver Installation - 🟢 INSTALLED Nov 13, 2025 (needs binding/config)

**In Progress**:
- **MOD-002A**: Analog Video System - Camera installed, GEPRC RAD ready to install (replaces failed TX800)

**Pending Modifications**:
- **MOD-002B**: Walksnail Avatar HD (parts delivered July 24, 2025) ✓ On hand - Backup if analog insufficient
- **MOD-002C**: HDZero Freestyle V2 - ➡️ REALLOCATED to RD-54 Zorro (Dec 2, 2025)
- **MOD-003**: RGB Arm LED Installation (parts acquired June 4, 2025) ✓ On hand
- **MOD-004**: VIFLY GPS-mate Power Module Installation (parts delivered July 24, 2025) ✓ On hand

See `RD-59_Modifications_Log.md` for complete modification details and installation checklists.

---

## Reference Documents

- **Factory Specifications**: `reference/Nazgul_DC5_ECO_Factory_Specs.md`
- **Google Photos Album**: [RD-59 Photo Gallery](https://photos.google.com/album/AF1QipMQ81SgmNKcywQYFzFxxncO6l4DfiegxZddzp05)
- **Local Photos**: `/Users/franconogarin/localcode/spyd.com/public/drone-lab/drones/RD-59/googlePhotos/`
- **Incident Log**: `RD-59_Incident_Log.md`
- **Modifications Log**: `RD-59_Modifications_Log.md`
- **Timeline**: `RD-59_Build_Timeline.md`

---

## Notes

**Important Reminders**:
- This aircraft was purchased as a partial build with critical systems removed
- DJI O4 system was factory-installed but removed by previous owner before sale
- Receiver was never included (not part of factory package)
- All flight electronics (FC, ESC, motors) are untested by current operator
- First test flight will establish operational baseline

**Next Steps**:
1. ✅ ~~Select and purchase receiver system~~ - **COMPLETE** (HappyModel ELRS EP1 Dual RX on hand)
2. ✅ ~~Select and purchase video system~~ - **COMPLETE** (Walksnail Avatar HD Moonlight on hand)

**PHASE 1: GET IT FLYING**
3. **Install and configure receiver** (MOD-001) - See installation checklist in Modifications Log
4. **Install and configure video system** (MOD-002) - See installation checklist in Modifications Log
5. **Perform bench testing** - Verify receiver and video operational
6. **Perform test flights and establish baseline** - First flights with current BLITZ stack
7. **Evaluate performance** - Assess BLITZ stack performance

**PHASE 2: ENHANCEMENTS (After flying)**
8. *Optional*: Install RGB LEDs (MOD-003)
9. *Optional*: Install GPS-mate (MOD-004)
10. *If needed*: Evaluate if SpeedyBee stack upgrade warranted

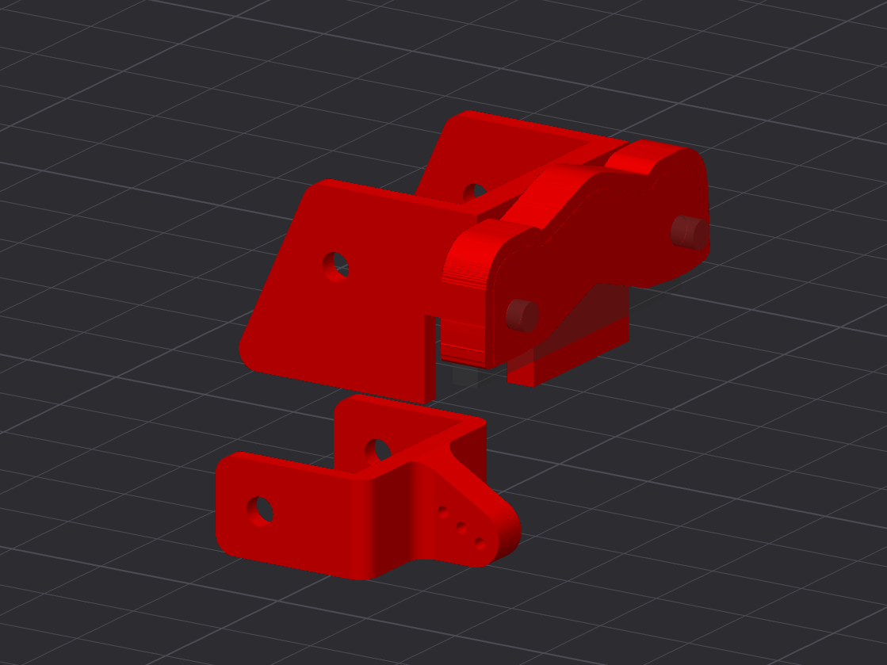
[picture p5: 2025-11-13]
custom parts/Screenshot 2025-11-13 at 7.17.47 AM.png

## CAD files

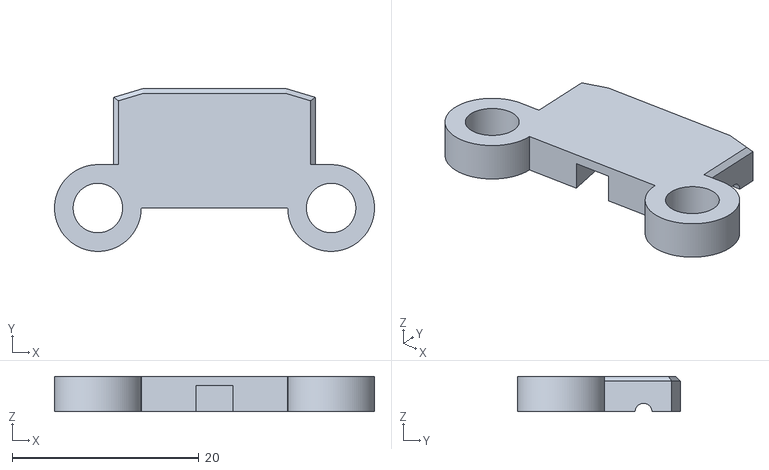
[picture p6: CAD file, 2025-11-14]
custom parts/antenna holder top/RadioMasterRp1Mount.stl
34.3 x 17.4 x 3.80

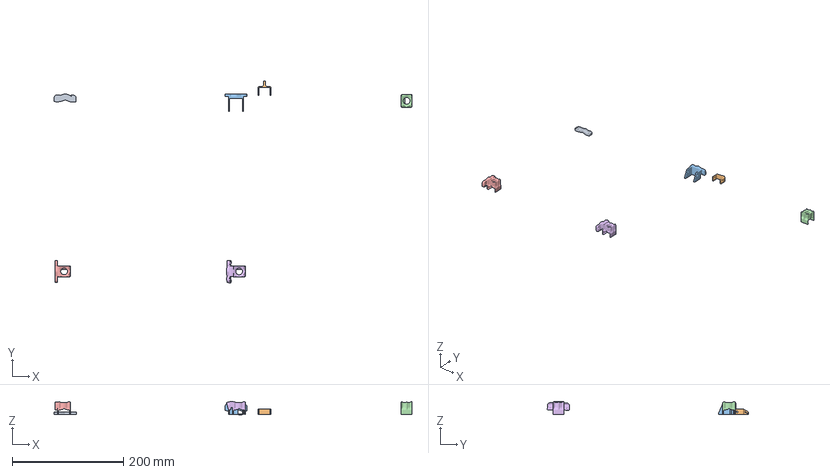
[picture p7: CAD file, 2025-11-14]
custom parts/Front Bumber TPU.3mf
643.7 x 362.3 x 24.2 mm
Front Bumber TPU
Camera servo mount
Bumper Mount
ratel-2-tpu-sock.stl
V2
Assembly

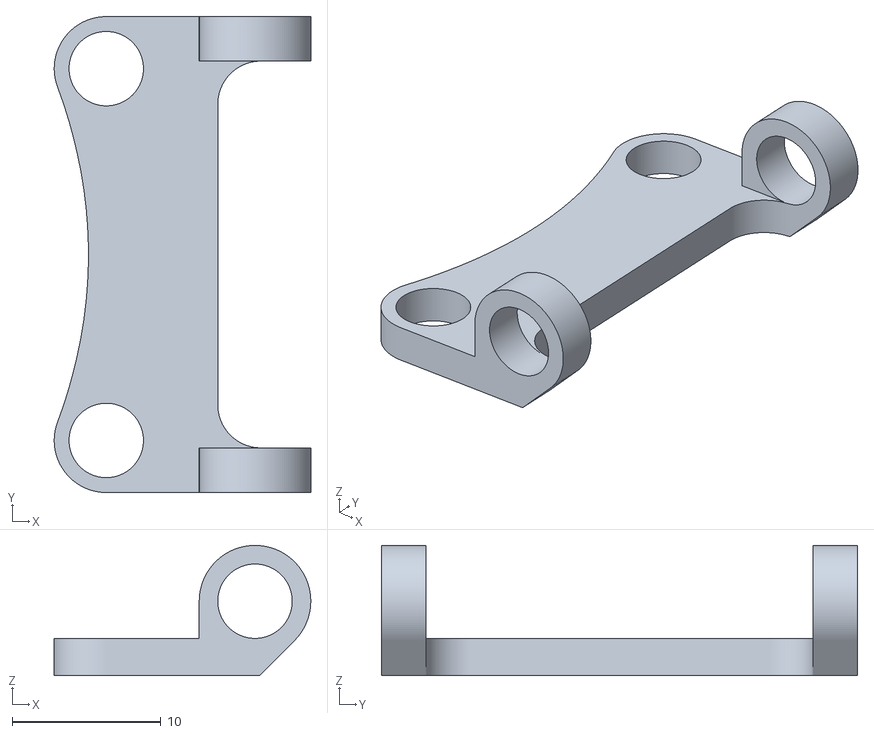
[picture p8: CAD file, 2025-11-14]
custom parts/antenna holder top/era-5inch-frame-crossfire-antenna-holder-v1.stl
17.2 x 32.0 x 8.75

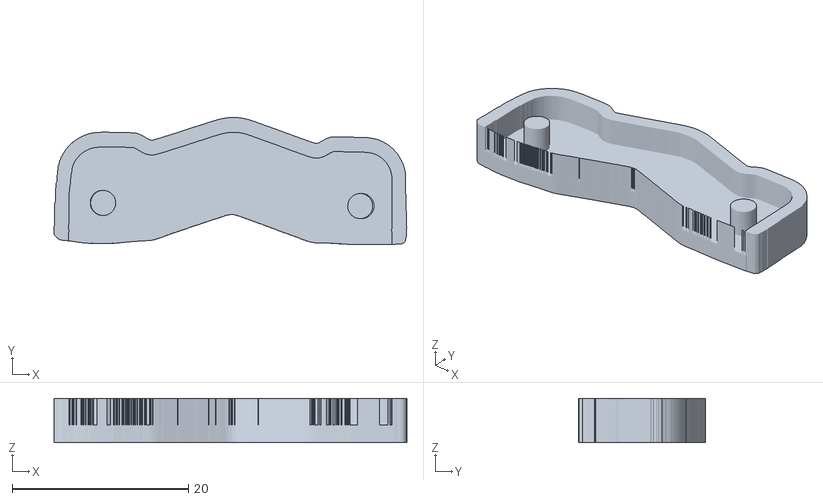
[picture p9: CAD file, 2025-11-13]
custom parts/Front Bumber TPU nazgul5 dc eco.stl
40.0 x 14.4 x 5.02

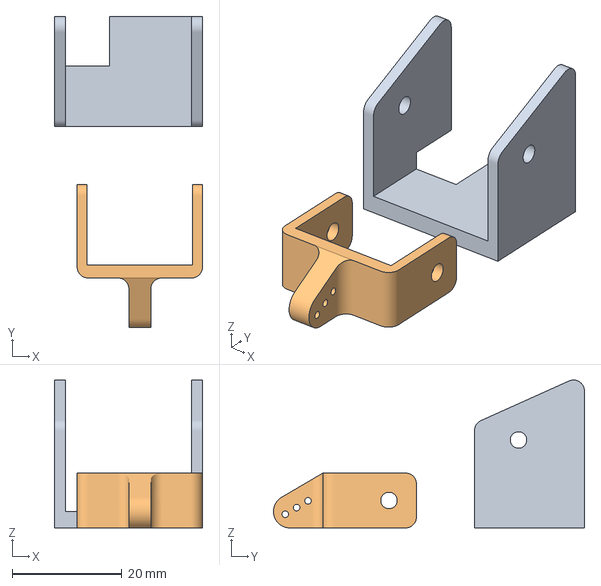
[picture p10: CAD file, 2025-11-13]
custom parts/PP_Camera+mount.3mf
27.0 x 56.5 x 26.9 mm
Camera mount
Camera servo mount

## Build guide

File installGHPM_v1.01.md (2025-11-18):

# GitHub Project Management Setup for Drone Projects v1.01

**Purpose**: This document provides a complete prompt for Claude Code to set up a comprehensive GitHub-based project management system for your drone build project.

**What This Sets Up**:

- GitHub CLI installation and authentication
- Custom issue labels for drone project tracking
- GitHub Project board for visual task management
- Milestones for tracking major build goals
- Initial issues for pending work
- Documentation in your CLAUDE.md file

---

## Prerequisites

Before starting, ensure:

- Your drone project is in a Git repository
- The repository has a GitHub remote configured
- You have a CLAUDE.md file (or are willing to create one)
- You're working on macOS (for Homebrew installation)

---

## The Prompt

Copy the text below and paste it into your Claude Code session:

---

### START OF PROMPT

I want you to set up a GitHub project management system for my drone build project. Please follow these steps:

### Step 1: Install and Configure GitHub CLI

1. Install GitHub CLI via Homebrew: `brew install gh`
2. Authenticate with GitHub: `gh auth login`
3. Request additional scopes for project management: `gh auth refresh -s project,read:project --hostname github.com`

### Step 2: Create Issue Labels

Create the following labels for my repository (replace `OWNER/REPO` with my actual GitHub repo):

**Task Type Labels**:

- `incident` (color: #d73a4a) - Crash reports and damage assessments
- `modification` (color: #0075ca) - Planned or in-progress modifications
- `parts-ordered` (color: #fbca04) - Parts ordered, awaiting delivery
- `pending-install` (color: #f9d0c4) - Parts received, awaiting installation
- `maintenance` (color: #d4c5f9) - Routine maintenance tasks
- `enhancement` (color: #a2eeef) - Improvements and upgrades

**Priority Labels**:

- `priority: critical` (color: #b60205) - Airworthiness/safety critical issues
- `priority: high` (color: #d93f0b) - Important but not safety critical

**Component Labels**:

- `video-system` (color: #c5def5) - FPV video system related
- `radio-system` (color: #bfdadc) - Radio/receiver related

Use the `gh label create` command for each label.

### Step 3: Create GitHub Project Board

1. Create a new project called "[MY DRONE NAME] Project Tracker" for my repository
2. Note the project number for future reference
3. The default columns (Todo, In Progress, Done) are fine

### Step 4: Create Milestones

Create the following milestones using the GitHub API (`gh api`):

1. **Working Video** - FPV video system installed and operational
2. **Working GPS** - GPS system installed, configured, and acquiring satellites
3. **Ready To Fly** - All critical systems operational and airworthy
4. **Maiden Flight** - First successful flight by current operator

### Step 5: Create Initial Issues

Based on my drone's current status, create GitHub issues for:

- Any missing components (receiver, video system, etc.)
- Pending installations
- Known problems or needed repairs

For each issue:

- Assign appropriate labels
- Assign to the relevant milestone
- Assign to me (the repository owner)
- Add to the project board

### Step 6: Update CLAUDE.md

Add a comprehensive "GitHub Issues & Project Management" section to my CLAUDE.md file that documents:

1. **Dual-Track Documentation System**: Explain that we use both Markdown docs (comprehensive archive) and GitHub Issues (active task tracking)

2. **GitHub Project Structure**: Document the project board number, milestones, and column structure

3. **Issue Label System**: List all labels and their purposes

4. **When to Create GitHub Issues**: Define when issues should be created (crashes, parts orders, modifications, bugs, maintenance)

5. **Issue Creation Workflow**: Step-by-step process for creating and documenting issues

6. **Integration Between Issues and Docs**: How to cross-reference between GitHub issues and Markdown documentation

7. **Common gh CLI Commands**: Provide a reference of frequently used commands including:
   - Creating issues with labels, assignee, and milestone
   - Listing issues by label or assignee
   - Updating issues
   - Closing issues
   - Adding issues to project board
   - Listing milestones

8. **Issue Lifecycle**: Explain the typical flow from creation to completion

9. **Best Practices**: Guidelines for issue titles, bodies, labels, and comments

10. **Milestone Assignment Guidelines**: Which types of issues go to which milestones

Also update the "Future Claude Instances" section to remind future Claude sessions to check open GitHub issues when starting work.

### Step 7: Commit Changes

Create a git commit documenting the GitHub project management setup with an appropriate commit message.

### Step 8: Provide Summary

Give me a summary of:

- What was set up
- Project board number and URL
- Number of labels created
- Number of milestones created
- Number of initial issues created
- How to access the project in VS Code or GitHub web

### END OF PROMPT

---

## Expected Outcome

After running this prompt, you will have:

✓ GitHub CLI installed and authenticated
✓ Custom issue labels tailored for drone projects
✓ A GitHub Project board for visual task management
✓ Four milestones tracking major build goals
✓ Initial issues created for your pending work
✓ Complete documentation in CLAUDE.md for future Claude sessions
✓ All changes committed to your repository

---

## Customization Options

You can customize the setup by:

1. **Adding/Removing Labels**: Adjust the label list based on your project needs
2. **Changing Milestones**: Modify milestone names/descriptions for your specific goals
3. **Additional Components**: Add component-specific labels (flight-controller, esc, motors, etc.)
4. **Priority Levels**: Add medium/low priority labels if needed
5. **Project Columns**: Customize the project board columns (add "Blocked", "Testing", etc.)

---

## Using the System

Once set up, Claude Code will automatically:

- Create GitHub issues when you report crashes, parts orders, or modifications
- Assign issues to you with appropriate labels and milestones
- Update Markdown documentation alongside GitHub issues
- Cross-reference between issues and documentation
- Track progress on the project board

You can access your issues and project board:

- **In VS Code**: GitHub Pull Requests and Issues extension (built-in)
- **On the Web**: <https://github.com/OWNER/REPO/issues> and <https://github.com/OWNER/REPO/projects>
- **Via CLI**: `gh issue list --repo OWNER/REPO`

---

## Maintenance

The system is self-maintaining through Claude Code, but you can:

- Review and close completed issues
- Move issues between project board columns
- Update milestone progress
- Add new labels as needed
- Create additional milestones for future goals

---

## Support

This project management system was developed for the RD-59 "Nazgul" drone project. The complete implementation and documentation can be found at: <https://github.com/spydmobile/RD59_Nazgul>

For questions or improvements, refer to the CLAUDE.md file in your repository after setup.

---

**Pro Tip**: After setup, ask Claude Code to "provide current status of [YOUR DRONE NAME]" to get a comprehensive status report including GitHub issue tracking, milestone progress, and airworthiness status.

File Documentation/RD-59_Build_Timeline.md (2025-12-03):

# RD-59 "Nazgul" Build Timeline

**Drone Designator**: RD-59
**Code Name**: Nazgul
**Operator**: SpyD (Franco Nogarin)
**Last Updated**: 2025-12-02

---

## Timeline Overview

**Project Start**: July 15, 2025 (Acquisition Date)
**Current Phase**: Pre-Flight Preparation (Final Steps)
**Days Since Acquisition**: 140 days (as of Dec 2, 2025)

---

## Chronological History

### Phase 0: Pre-Acquisition (Unknown - July 15, 2025)

#### Factory Build
- **Original Build**: Nazgul DC5 ECO V1.1 assembled by iFlight
- **Factory Configuration**: Complete aircraft with DJI O4 Air Unit Pro
- **Original Owner**: Unknown (purchased by Devon "Toasty" Felker)

#### Previous Owner Period
- **Owner**: Devon "Toasty" Felker
- **Location**: Hay River
- **Modifications by Previous Owner**:
  - Removed DJI O4 Air Unit Pro (camera + VTX)
  - Removed GoPro (if one was installed)
  - Note: No receiver was ever installed (not included in factory package)
- **Duration of Ownership**: Unknown
- **Flight History**: Unknown

---

### Phase 0.5: Pre-Acquisition Parts Procurement (June 2025)

#### June 4, 2025 - ELRS Receiver & LED Purchase ✓
- **Parts Acquired** (before RD-59 acquisition):
  - HappyModel ExpressLRS TCXO EP1 Dual RX
  - SpeedyBee Programmable 2812 Arm LEDs (4 pcs)
- **Context**: Parts purchased for general use, not specifically for RD-59
- **Later Applied**: These parts later designated for RD-59 installation (MOD-001, MOD-003)

**Lessons Learned**:
- Having ELRS receiver on hand accelerated RD-59 readiness
- Generic FPV parts procurement paid off when acquiring partial build

---

### Phase 1: Acquisition (July 2025)

#### July 14, 2025 - Pre-Purchase Documentation
- **Photos taken**: Initial documentation photos captured
  - Photos available at: `/Users/franconogarin/localcode/spyd.com/public/drone-lab/drones/RD-59/googlePhotos/`
  - Timestamps: July 14, 2025 at 16:55:46 and 17:13:37

#### July 15, 2025 - Acquisition Day ✓
- **Transaction Completed**
  - Purchased from: Devon "Toasty" Felker
  - Location: Hay River
  - Purchase Price: $273.12 CAD
  - Condition: Partial build - missing video system, no receiver
- **Photos taken**: Additional documentation at 12:35:11
- **Initial Assessment**:
  - Frame: Complete and undamaged
  - Flight electronics: Present (FC, ESC, motors)
  - GPS: Present
  - Battery connector: XT60 with anti-spark
  - Props: Nazgul F5 included
  - Missing: DJI O4 video system (removed)
  - Missing: Receiver (never installed)

**Lessons Learned**:
- Aircraft purchased as partial build with known missing components
- Previous owner removed video system, reducing value but also cost
- Provides opportunity to select preferred video system (analog vs digital)

---

### Phase 2: Pre-Flight Preparation (July 15, 2025 - Present)

#### July 17, 2025 - Parts Ordered ✓
- **Decision Made**: Walksnail Avatar HD selected for video system
- **Rationale**:
  - Operator moved away from DJI ecosystem ($10k invested, no longer using)
  - Considerable investment in Goggles X (Avatar compatible)
  - Onboard HD recording capability important to operator
- **Parts Ordered**:
  - Walksnail Avatar HD Moonlight VTX Kit
  - Gemfan 51433 Hurricane Tri-Blade Props (lemon yellow x2, dark grey x2)
  - GNB 1350mAh 6S 100C LiPo XT60 (x4)
  - SpeedyBee F7 50A V3 Combo Stack (future consideration)
  - VIFLY GPS-mate External GPS Power Module w/ Built-In Finder 2 Buzzer

**Decisions Made**:
- ✅ Receiver: HappyModel ELRS EP1 Dual RX (already owned)
- ✅ Video system: Walksnail Avatar HD Moonlight (ordered)
- ✅ Batteries: GNB 1350mAh 6S 100C (ordered)
- ✅ Props: Gemfan Hurricane 51433 with color scheme for DeadCat frame

#### July 24, 2025 - Parts Delivered ✓
- **All ordered parts received**
- **Inventory Status**: All critical components on hand
  - MOD-001 (ELRS receiver): Ready
  - MOD-002 (Walksnail video): Ready
  - MOD-003 (RGB LEDs): Ready
  - MOD-004 (GPS-mate): Ready
- **Aircraft Status**: Ready for installation work

**Lessons Learned**:
- 7-day turnaround from order to delivery (July 17 → July 24)
- All critical airworthiness components acquired within 9 days of drone purchase

#### July 24 - November 1, 2025 - Waiting Period
- **Current Status**: Aircraft stored, all parts on hand, awaiting installation
- **Duration**: 100 days between parts arrival and next action

#### November 2, 2025 - HDZero System Ordered ✓
- **Strategic Decision**: Ordered HDZero system to evaluate as daily driver goggles for FPV fleet
- **Parts Ordered**:
  - HDZero Goggle 2 (red) with Echo Antenna Kit - $679.99
  - HDZero Freestyle V2 Kit - $149.99
  - Total Investment: $829.98
- **Strategic Rationale**:
  - **Fleet Context**: Operator has:
    - DJI Mini Pro 4 (complete setup) - cinematic/AP platform
    - Goggles X + 3 Walksnail drones (RD-54 Zorro, RD-55 Flylens75, RD-59 Nazgul) - FPV fleet
  - **Goal**: Transition HDZero Goggle 2 to become daily driver for FPV operations
  - **Test Platform**: Use RD-59 to evaluate HDZero before potentially retrofitting RD-54 & RD-55
  - **Fleet-wide implications**: If HDZero succeeds on RD-59, may convert RD-54 & RD-55 from Walksnail to HDZero
  - **Lower latency**: HDZero's responsiveness advantage over Walksnail critical for FPV
  - **Ecosystem separation**: DJI for cinematic/AP, HDZero for FPV racing/freestyle
  - **New to HDZero**: First experience with HDZero ecosystem
- **Expected Delivery**: Week of November 9, 2025

#### November 10, 2025 - Documentation & Planning
- **Documentation Created**:
  - Repository established for RD-59 Nazgul
  - As-built parts list documented
  - Factory specifications captured
  - Modifications log with MOD-001 through MOD-005 detailed
  - Complete installation checklists prepared
  - HDZero option documented (MOD-002C)

#### November 13, 2025 - MOD-001 & MOD-002A Installation ✓
- **ELRS Receiver Installed (MOD-001)**:
  - HappyModel EP1 Dual RX soldered to UART3
  - Dual antennas routed (90° diversity achieved)
  - Awaiting binding and configuration
- **Analog Video Hardware Installed (MOD-002A)**:
  - CADDX Ratel 2 camera mounted in custom TPU V3 bumper
  - SpeedyBee TX800 VTX installed
  - TrueRC CORE antenna mounted

#### November 14, 2025 - TX800 Bench Test FAILED ✗
- **Bench Test Results**:
  - VTX communication working (IRC Tramp, Device ready: True)
  - **NO VIDEO OUTPUT** - LED indicates no camera signal
  - **EXCESSIVE HEAT** - VTX dangerously hot even in pit mode
- **Decision Made**: Replace TX800 with GEPRC RAD Mini 1W ($74)
- **Rationale**: Operator already happy with GEPRC RAD from other builds

#### December 2, 2025 - Parts Arrived & Video Path Confirmed ✓
- **Parts Delivered**:
  - GEPRC RAD Mini 1W - ✓ ARRIVED (replaces failed TX800)
  - HDZero Goggle 2 (red) with Echo Antenna Kit - ✓ ARRIVED
  - HDZero Freestyle V2 Kit - ✓ ARRIVED
- **Strategic Decision**: HDZero VTX reallocated to RD-54 "Zorro"
  - RD-54 becomes HDZero evaluation platform
  - RD-59 confirmed for analog (MOD-002A) - maximize flight time for cruiser role
- **Video Path Confirmed**: Analog (GEPRC RAD + Ratel 2) with Walksnail as backup only

**Current Blockers**:
- ⏳ GEPRC RAD not yet installed - Parts on hand, ready for installation
- ⏳ ELRS receiver needs binding/configuration
- ⏳ Bench test required after VTX swap

---

## Future Planned Activities

### Phase 3: Component Selection & Ordering ✅ COMPLETED

**Objectives**: ✅ All objectives met
- ✅ Select and order receiver system
- ✅ Select and order video system
- ✅ Plan installation sequence

**Tasks Completed**:
- [x] Research ELRS receiver options (completed before June 4)
- [x] Research video system options (completed before July 17)
- [x] Make final component selections (Walksnail Avatar HD selected)
- [x] Order receiver system (already owned as of June 4)
- [x] Order video system (ordered July 17)
- [x] Receive and inventory parts (delivered July 24)

**Actual Duration**: 7 days (July 17 order → July 24 delivery)
**Phase Completed**: July 24, 2025

---

### Phase 4: Critical Installations (TBD)

**Objectives**:
- Install receiver and video system (MOD-001 + MOD-002)
- Configure all electronics
- Get aircraft flying

**Installation Plan**: Install RX + VTX → Get it flying → Everything else comes later

**Phase 4a: Receiver Installation (MOD-001)**
- [ ] Install HappyModel ELRS EP1 Dual RX
- [ ] Wire receiver to FC (TX/RX/VCC/GND)
- [ ] Route dual antennas for optimal diversity
- [ ] Configure ELRS in Betaflight
- [ ] Bind receiver to transmitter
- [ ] Test control inputs and failsafe

**Phase 4b: Video System Installation (MOD-002)**
- [ ] Install Walksnail Avatar HD Moonlight VTX Kit
- [ ] Mount Moonlight camera
- [ ] Wire VTX to FC (UART for MSP) and power (VBAT/GND)
- [ ] Route and secure VTX antenna
- [ ] Configure MSP and OSD in Betaflight
- [ ] Test video feed with Goggles X
- [ ] Verify HD recording functionality

**Phase 4c: Bench Testing & Preparation**
- [ ] Bench test all systems together
- [ ] Verify all functions operational
- [ ] Pre-flight safety checks
- [ ] Update documentation

**Estimated Duration**: 1-2 days (depending on complexity)

---

### Phase 5: Test Flights & Baseline Establishment (TBD)

**Objectives**:
- Perform first test flights
- Establish operational baseline
- Tune and optimize as needed

**Tasks**:
- [ ] Pre-flight inspection
- [ ] First hover test (LOS)
- [ ] First FPV test flight
- [ ] PID tuning as needed
- [ ] Video quality assessment
- [ ] Range testing
- [ ] Document baseline performance
- [ ] Update parts list with test results

**Estimated Duration**: 1-2 weeks (weather dependent)

---

### Phase 6: Optional Enhancements (TBD)

**Objectives**:
- Install optional enhancements (MOD-003, MOD-004)
- Improve visibility, GPS performance, and lost model recovery

**Prerequisites**: Complete Phase 5 test flights and establish baseline performance

**Tasks**:
- [ ] Install RGB Arm LEDs (MOD-003) - SpeedyBee 2812 LEDs
- [ ] Configure LED patterns in Betaflight
- [ ] Test LED functionality
- [ ] Install VIFLY GPS-mate power module (MOD-004)
- [ ] Configure Finder 2 buzzer
- [ ] Test GPS performance improvement
- [ ] Test lost model buzzer functionality
- [ ] Update documentation

**Estimated Duration**: 1 day

**Note**: These are optional enhancements. Skip this phase if baseline performance is satisfactory and enhancements not desired.

---

### Phase 7: Operational Status (TBD)

**Objectives**:
- Achieve full operational status
- Regular flight operations
- Ongoing maintenance

**Expected Activities**:
- Regular flight sessions
- Maintenance as needed
- Performance monitoring
- Incident response (if any)
- Upgrades/modifications as desired

---

## Project Statistics

### Time Investment

| Phase | Start Date | End Date | Duration | Status |
|---|---|---|---|---|
| **Pre-Acquisition Parts** | June 4, 2025 | June 4, 2025 | 1 day | Completed |
| **Pre-Acquisition** | Unknown | July 15, 2025 | Unknown | Completed |
| **Acquisition** | July 15, 2025 | July 15, 2025 | 1 day | Completed |
| **Component Selection** | July 15, 2025 | July 24, 2025 | 9 days | Completed |
| **Pre-Flight Prep** | July 24, 2025 | Present | 109 days | In Progress |
| **Installation** | TBD | TBD | TBD | Pending |
| **Test Flights** | TBD | TBD | TBD | Pending |
| **Operational** | TBD | Ongoing | Ongoing | Pending |

**Days Since Acquisition**: 140 days (July 15 - Dec 2, 2025)
**Days Parts On Hand**: 131 days (July 24 - Dec 2, 2025)

### Cost Tracking

| Category | Amount (CAD) | Date | Notes |
|---|---|---|---|
| **ELRS Receiver + LEDs** | Price not recorded | June 4, 2025 | HappyModel EP1 Dual RX + SpeedyBee RGB LEDs x4 |
| **Initial Purchase** | $273.12 | July 15, 2025 | Partial aircraft from Toasty |
| **Video System** | Price not recorded | July 17, 2025 | Walksnail Avatar HD Moonlight VTX Kit |
| **Batteries (x4)** | Price not recorded | July 17, 2025 | GNB 1350mAh 6S 100C XT60 |
| **Props** | Price not recorded | July 17, 2025 | Gemfan 51433 Hurricane x4 sets |
| **GPS-mate** | Price not recorded | July 17, 2025 | VIFLY GPS-mate w/ Finder 2 |
| **SpeedyBee Stack** | Price not recorded | July 17, 2025 | F7 50A V3 Combo (future consideration) |
| **HDZero Goggle 2** | $679.99 | Nov 2, 2025 | HDZero Goggle 2 (red) with Echo Antenna Kit |
| **HDZero VTX** | $149.99 | Nov 2, 2025 | HDZero Freestyle V2 Kit (➡️ reallocated to RD-54) |
| **GEPRC RAD Mini 1W** | $74.00 | Nov 14, 2025 | Replacement for failed TX800 |
| **Total Recorded** | $1,177.10+ | | Plus unrecorded parts costs from June/July |

**Note**: Exact costs for parts ordered June 4 and July 17 not documented. Consider updating with actual costs if desired.

### Flight Hours

| Metric | Value |
|---|---|
| **Total Flight Time** | 0 hours |
| **Flights by Current Operator** | 0 |
| **Flights by Previous Owner** | Unknown |

---

## Key Milestones

- ✅ **June 4, 2025**: ELRS receiver and RGB LEDs acquired
- ✅ **July 15, 2025**: Aircraft acquired from Devon "Toasty" Felker
- ✅ **July 17, 2025**: Video system, batteries, props, and accessories ordered
- ✅ **July 24, 2025**: All ordered parts delivered - aircraft ready for installation
- ✅ **November 2, 2025**: HDZero system ordered ($829.98 investment)
- ✅ **November 10, 2025**: Documentation repository established
- ✅ **November 13, 2025**: ELRS receiver installed (MOD-001), analog video hardware installed
- ✅ **November 14, 2025**: TX800 bench test FAILED - GEPRC RAD ordered as replacement
- ✅ **December 2, 2025**: GEPRC RAD & HDZero arrived; HDZero reallocated to RD-54; analog path confirmed
- ⏳ **TBD**: GEPRC RAD installed, video bench test passed
- ⏳ **TBD**: ELRS receiver bound and configured
- ⏳ **TBD**: First test flight with analog system
- ⏳ **TBD**: Optional enhancements installed (MOD-003, MOD-004)
- ⏳ **TBD**: Operational status achieved
- ⏳ **TBD**: Decision on SpeedyBee stack upgrade (if needed)

---

## Lessons Learned

### From Acquisition (July 2025)
1. **Partial builds can be good value** - Purchasing aircraft without video system saved money and provides flexibility for system selection
2. **Know what's missing** - Clear understanding of missing components allowed accurate pricing and planning
3. **Documentation matters** - Photos from July 14-15 provide valuable reference for as-purchased condition
4. **Having parts on hand pays off** - ELRS receiver already owned before acquisition accelerated readiness

### From Parts Selection (July 2025)
1. **Ecosystem matters** - Moving away from DJI ($10k invested) influenced choice of Walksnail Avatar
2. **Existing investment drives decisions** - Goggles X ownership made Avatar HD the logical choice
3. **Fast parts turnaround** - 7-day delivery (July 17 → 24) enabled quick progression
4. **Smart prop color scheme** - Lemon yellow rear, dark grey front keeps props out of FPV camera (DeadCat design)
5. **Future-proofing** - Purchasing SpeedyBee stack as backup option provides insurance if BLITZ stack underperforms
6. **Battery selection strategy** - 1350mAh (vs factory 1480mAh) chosen for lighter build without action cam, better power-to-weight for freestyle

### From Documentation (November 2025)
1. **Document early and accurately** - 109 days between parts arrival and documentation - earlier would be better
2. **Capture rationale** - Recording "why" decisions were made (DJI ecosystem exit) provides valuable context
3. **Track all dates** - Having specific dates (June 4, July 17, July 24, Nov 2) creates clear timeline
4. **Multiple options create flexibility** - Having both Walksnail and HDZero available allows data-driven decision after analog testing
5. **Strategic fleet planning** - $830 HDZero investment is fleet-wide evaluation, not just for RD-59
6. **Test before committing fleet** - RD-59 serves as HDZero test platform before converting other aircraft from Walksnail
7. **Separate ecosystems by use case** - DJI for cinematic (Mini Pro 4), HDZero target for FPV racing/freestyle

### Future Lessons
*(To be added as installations and test flights progress)*

---

## Related Documents

- **Parts List**: `RD-59_AsBuilt_Parts_List.md`
- **Incident Log**: `RD-59_Incident_Log.md`
- **Modifications**: `RD-59_Modifications_Log.md`
- **Factory Specs**: `reference/Nazgul_DC5_ECO_Factory_Specs.md`
- **Photo Gallery**: [Google Photos Album](https://photos.google.com/album/AF1QipMQ81SgmNKcywQYFzFxxncO6l4DfiegxZddzp05)

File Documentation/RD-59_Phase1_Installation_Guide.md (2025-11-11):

# RD-59 "Nazgul" Phase 1 Installation Guide

**Drone Designator**: RD-59
**Code Name**: Nazgul
**Operator**: SpyD (Franco Nogarin)
**Created**: 2025-11-10
**Status**: Pre-Installation Planning

---

## Overview

This guide provides step-by-step instructions for Phase 1 installations on RD-59, using specific wiring details from the BLITZ ATF435 flight controller diagram.

**Phase 1 Objective**: Install receiver and analog video system to achieve minimum flight capability

**Modifications Covered**:
- MOD-001: ELRS Receiver Installation
- MOD-002A: Analog Video System Installation (TX800 + Ratel 2)

---

## Prerequisites

### Tools Required
- Soldering iron (temperature-controlled recommended)
- Solder (60/40 or 63/37 rosin core)
- Wire strippers
- Heat shrink tubing
- Hot air gun or lighter (for heat shrink)
- Double-sided mounting tape
- Hex drivers (for frame disassembly if needed)
- Multimeter (for continuity testing)

### Parts Required
- [x] HappyModel ExpressLRS TCXO EP1 Dual RX (on hand since June 4, 2025)
- [x] SpeedyBee TX800 VTX (on hand, liberated from 3.5" build)
- [x] CADDX Ratel 2 camera (red) (on hand)
- [x] VTX antenna (included with TX800)
- [ ] VTX mounting standoffs (verify TX800 includes them - CRITICAL)

### Pre-Installation Checks
- [ ] Verify TX800 VTX is functional (bench test recommended due to previous shorting issues)
- [ ] Verify TX800 includes proper standoffs (prevents shorting to FC/frame)
- [ ] Verify ELRS receiver antennas are intact
- [ ] Verify camera lens is clean and undamaged
- [ ] Have analog goggles available for video testing

---

## BLITZ ATF435 Flight Controller Reference

### UART Assignments (Recommended)

| UART | Pads | Assignment | Purpose |
|---|---|---|---|
| **UART2** | R2/T2 | ELRS Receiver | Control link (CRSF protocol) |
| **UART1** | R1/T1 | TX800 VTX | SmartAudio/Tramp control |
| UART3 | R3/T3 | Available | (Alternative for VTX if needed) |
| UART4 | R4/T4 | Available | (Future use) |
| UART5 | R5/T5 | Available | (Future use) |
| UART6 | R6 | Available | (Future use) |

**Note**: SDA/SCL pads are for GPS (I2C) and cannot be remapped to UART

### Power Rails Available

| Power Rail | Voltage | Use Case |
|---|---|---|
| **VBAT** | Battery voltage (22.2V nominal for 6S) | VTX power, high-power peripherals |
| **9V** | Regulated 9V | (Not needed for Phase 1) |
| **5V** | Regulated 5V | Receiver power, camera power |
| **3.3V** | Regulated 3.3V | (Internal FC use) |
| **GND** | Ground | All components |

### FC Status LEDs (Reference)

| LED Color | Meaning |
|---|---|
| Blue | Flashing during startup |
| Red | 3.3V power indicator |
| Orange | VBAT power indicator |
| Green | 5V BEC power indicator |

**Expected on Power-Up**: Red, Orange, and Green LEDs should illuminate

---

## MOD-001: ELRS Receiver Installation

### Step 1: Physical Mounting

**Mounting Location Options**:
- Between FC and top plate (typical)
- Under FC (if space available)
- Side-mounted on frame standoffs

**Installation**:
1. Determine best mounting location (access to R2/T2/5V/GND pads on FC)
2. Clean mounting surface with isopropyl alcohol
3. Apply double-sided mounting tape to receiver
4. Position receiver for easy access to antenna routing
5. Press firmly to secure

### Step 2: Antenna Routing

**Critical**: Dual antennas must be positioned at ~90° to each other for optimal diversity reception

**Routing Strategy**:
- Antenna 1: Route to rear-left, secure to rear arm
- Antenna 2: Route to rear-right, secure to rear arm
- Ensure antennas exit frame at different angles (avoid parallel)
- Use heat shrink or zip ties to secure antenna wires to frame
- Keep antennas away from carbon fiber and metal (RF blocking)

### Step 3: Wiring to FC

**Wire Connections** (UART2 - R2/T2 pads):

| Receiver Wire | FC Pad | Purpose | Notes |
|---|---|---|---|
| RX (receiver input) | T2 | FC transmits data to receiver | Yellow/white wire typical |
| TX (receiver output) | R2 | Receiver transmits data to FC | Green/white wire typical |
| VCC (power) | 5V | Receiver power (5V regulated) | Red wire typical |
| GND (ground) | GND | Common ground | Black wire typical |

**Soldering Steps**:
1. Tin all four receiver wires
2. Tin R2, T2, 5V, and GND pads on FC
3. Solder RX wire to T2 pad (FC transmits to receiver)
4. Solder TX wire to R2 pad (Receiver transmits to FC)
5. Solder VCC wire to 5V pad
6. Solder GND wire to GND pad
7. Verify all joints are shiny and secure (no cold solder joints)
8. Apply heat shrink over exposed solder joints (optional but recommended)

**Common Mistake**: Swapping RX/TX - Remember: Receiver RX connects to FC TX (and vice versa)

### Step 4: Betaflight Configuration

**Ports Tab**:
1. Connect FC to Betaflight Configurator via USB
2. Navigate to **Ports** tab
3. Find **UART2** row
4. Set **Serial RX** in dropdown
5. Click **Save and Reboot**

**Configuration Tab**:
1. Navigate to **Configuration** tab
2. Scroll to **Receiver** section
3. Set **Receiver Protocol** to **CRSF**
4. Click **Save and Reboot**

### Step 5: Binding & Testing

**Binding Procedure**:
1. Put ELRS transmitter into bind mode (refer to transmitter manual)
2. Power on RD-59 with battery (expect receiver LED to flash rapidly)
3. Wait for bind confirmation (receiver LED solid or slow blink)
4. Power cycle aircraft to confirm bind persists

**Control Testing**:
1. Navigate to **Receiver** tab in Betaflight
2. Move sticks on transmitter
3. Verify all channels respond correctly:
   - Roll (Aileron) - Channel 1
   - Pitch (Elevator) - Channel 2
   - Throttle - Channel 3
   - Yaw (Rudder) - Channel 4
   - Arm switch - Channel 5 (or configured channel)
4. Verify channel ranges (typically 1000-2000)

**Failsafe Configuration**:
1. Navigate to **Failsafe** tab
2. Set desired failsafe behavior (typically "Drop" for throttle)
3. Configure failsafe stage 2 (land or no pulses)
4. Test failsafe by powering off transmitter (verify aircraft disarms)

**RSSI Verification**:
1. Power on transmitter and aircraft
2. Check RSSI value in Betaflight (should show signal strength)
3. Walk away with transmitter to test range (optional bench test)

**Completion**: MOD-001 complete when all controls respond and failsafe works correctly

---

## MOD-002A: Analog Video System Installation

### Step 0: Pre-Installation Bench Test

**CRITICAL**: TX800 suspected of shorting issues on previous 3.5" build

**Bench Test Procedure**:
1. Connect TX800 to power supply (7.4V-25.2V capable, or old battery)
2. Connect CADDX Ratel 2 camera to TX800 video input
3. Power on TX800 (check for LED indicator)
4. Check video output with analog goggles/receiver
5. Verify SmartAudio/Tramp control works (if testable)
6. **If TX800 shows issues**: Consider replacement before installation

**Standoff Verification**:
- Verify TX800 includes proper standoffs for mounting
- Standoffs must provide clearance from FC and frame (prevents shorting)
- If standoffs missing: source replacements before proceeding

### Step 1: Camera Installation

**Camera Mounting**:
1. Install camera mount on front of frame (if not already present)
2. Determine camera angle (20-40° typical for freestyle, 30° recommended starting point)
3. Mount CADDX Ratel 2 camera with appropriate angle
4. Secure camera with included screws/hardware
5. Route camera wire toward VTX mounting location

**Camera Angle Guide**:
- 20-25°: Cruising/cinematic flying
- 30-35°: Balanced freestyle/racing
- 40-50°: Aggressive racing

### Step 2: VTX Physical Installation

**CRITICAL SAFETY NOTE**: TX800 MUST be mounted with standoffs to prevent shorting to FC or carbon fiber frame

**VTX Mounting**:
1. Position TX800 on stack with standoffs installed
2. Verify standoffs provide 3-5mm clearance from FC below
3. Verify no metal surfaces can contact VTX circuit board
4. Secure VTX with screws through standoffs
5. Position for easy antenna connector access

**Antenna Installation**:
1. Thread antenna wire through frame (route away from carbon fiber)
2. Attach antenna to TX800 SMA/U.FL connector
3. **NEVER power VTX without antenna connected** (immediate damage)
4. Secure antenna wire to frame with zip tie/heat shrink
5. Position antenna for clear signal path (not blocked by frame/props)

### Step 3: Camera to VTX Wiring

**Connection**:
- Camera video output (yellow wire typical) → VTX video input
- Camera ground (black wire typical) → VTX ground
- Camera power (red wire typical) → VTX camera power output (5V typically)

**Note**: TX800 likely provides regulated power for camera - verify in TX800 manual

### Step 4: VTX to FC Wiring

**Power Connections**:

| VTX Wire | FC Pad | Purpose | Notes |
|---|---|---|---|
| VTX + (power) | VBAT | Battery voltage power | Red wire typical, check TX800 voltage range (should support 6S) |
| VTX - (ground) | GND | Common ground | Black wire typical |

**Control Connections (UART1 - R1/T1 pads)**:

| VTX Wire | FC Pad | Purpose | Notes |
|---|---|---|---|
| VTX TX (audio out) | R1 | VTX transmits SmartAudio/Tramp to FC | Yellow/white wire typical |
| VTX RX (audio in) | T1 | FC transmits commands to VTX (optional) | Green/white wire typical, may not be needed for all protocols |

**Soldering Steps**:
1. Tin all VTX wires
2. Tin VBAT, GND, R1, T1 pads on FC
3. Solder VTX power (+) wire to VBAT pad
4. Solder VTX ground (-) wire to GND pad
5. Solder VTX TX wire to R1 pad (for SmartAudio/Tramp)
6. Solder VTX RX wire to T1 pad (if bidirectional control needed)
7. Verify all joints are secure
8. Apply heat shrink over exposed joints

**Final Wiring Check**:
- [ ] No wires touching propeller path
- [ ] All joints secure and insulated
- [ ] Antenna securely attached
- [ ] Camera securely mounted
- [ ] VTX mounted with standoffs (clearance verified)

### Step 5: Betaflight Configuration

**Ports Tab**:
1. Navigate to **Ports** tab in Betaflight
2. Find **UART1** row
3. Set peripherals based on TX800 protocol:
   - If **SmartAudio**: Select **VTX (TBS SmartAudio)**
   - If **IRC Tramp**: Select **VTX (IRC Tramp)**
4. Click **Save and Reboot**

**Video Transmitter Tab**:
1. Navigate to **Video Transmitter** tab
2. Enable VTX control
3. Configure VTX Table (5.8GHz bands and channels):
   - Band A (Boscam A): 5865, 5845, 5825, 5805, 5785, 5765, 5745, 5725 MHz
   - Band B (Boscam B): 5733, 5752, 5771, 5790, 5809, 5828, 5847, 5866 MHz
   - Band E (Boscam E): 5705, 5685, 5665, 5645, 5885, 5905, 5925, 5945 MHz
   - Band F (Fatshark/Airwave): 5740, 5760, 5780, 5800, 5820, 5840, 5860, 5880 MHz
   - Band R (Raceband): 5658, 5695, 5732, 5769, 5806, 5843, 5880, 5917 MHz
4. Set power levels:
   - Level 1: 25mW (pit mode for bench testing)
   - Level 2: 200mW (medium range)
   - Level 3: 800mW (maximum range)
5. Click **Save and Reboot**

**OSD Tab**:
1. Navigate to **OSD** tab
2. Configure OSD layout with desired elements:
   - **Critical**: Battery voltage, RSSI, flight time, armed indicator
   - **Useful**: Throttle position, altitude, GPS coordinates (if using GPS)
   - **Optional**: Current draw, mAh consumed, artificial horizon
3. Position elements on screen (drag and drop)
4. Click **Save**

### Step 6: Video System Testing

**Initial Power-Up** (CRITICAL SAFETY):
1. Verify antenna is connected to TX800 (NEVER power VTX without antenna)
2. Set VTX to **pit mode (25mW)** for initial testing
3. Power on aircraft with battery
4. Verify TX800 LED indicator (should show power/activity)

**Video Feed Test**:
1. Power on analog goggles and set to match TX800 frequency
2. Verify video feed appears in goggles
3. Check video quality (should be clear analog image)
4. Verify OSD elements appear on screen
5. Check for interference or noise

**SmartAudio/Tramp Control Test**:
1. Access VTX menu via OSD (stick commands or OSD menu)
2. Test changing VTX band/channel
3. Test changing VTX power level (25mW → 200mW → 800mW)
4. Verify changes take effect (goggles should show signal strength change)

**Range Test** (optional bench test):
1. Set VTX to 800mW
2. Walk away with goggles to test range
3. Verify video remains clear at expected distances

**Final Video Checks**:
- [ ] Video feed clear and stable
- [ ] OSD elements visible and accurate
- [ ] Battery voltage displayed correctly
- [ ] RSSI displayed correctly (from ELRS receiver)
- [ ] VTX power level changes work
- [ ] VTX channel changes work

**Completion**: MOD-002A complete when video feed is clear and all OSD/VTX controls work

---

## Phase 1 Completion Checklist

### MOD-001: ELRS Receiver
- [ ] Receiver physically mounted
- [ ] Antennas routed at 90° diversity
- [ ] Wired to UART2 (R2/T2/5V/GND)
- [ ] Betaflight configured (UART2 Serial RX, CRSF protocol)
- [ ] Bound to transmitter
- [ ] All control channels responding correctly
- [ ] Failsafe configured and tested
- [ ] RSSI displaying in OSD

### MOD-002A: Analog Video System
- [ ] TX800 bench tested (functional, no shorting)
- [ ] Camera mounted with appropriate angle
- [ ] TX800 mounted with standoffs (clearance verified)
- [ ] Antenna connected and secured
- [ ] Camera wired to VTX
- [ ] VTX wired to FC (VBAT/GND for power, R1/T1 for control)
- [ ] Betaflight configured (UART1 VTX, VTX table, OSD layout)
- [ ] Video feed clear and stable
- [ ] OSD elements displayed correctly
- [ ] SmartAudio/Tramp control working
- [ ] Power level switching tested (25/200/800mW)

### Pre-Flight Checks
- [ ] All solder joints secure and insulated
- [ ] No wires in propeller path
- [ ] All components secured (no loose parts)
- [ ] Battery connector secure
- [ ] Propellers installed correctly (check direction and tightness)
- [ ] FC status LEDs normal (Red, Orange, Green on power-up)
- [ ] GPS lock achieved (if applicable)
- [ ] Aircraft arms successfully (via transmitter switch)
- [ ] Aircraft disarms successfully (via transmitter switch)
- [ ] Motors spin in correct direction (test with props off!)

### Documentation Updates
- [ ] Update RD-59_AsBuilt_Parts_List.md (mark MOD-001 and MOD-002A as operational)
- [ ] Update RD-59_Modifications_Log.md (mark MOD-001 and MOD-002A as completed)
- [ ] Update RD-59_Build_Timeline.md (add installation completion date)
- [ ] Take photos of completed installation for reference

---

## Next Steps After Phase 1

Once Phase 1 is complete, proceed to:

1. **Pre-flight Testing**:
   - Bench test with battery (props off)
   - Verify motor directions
   - Test arm/disarm
   - Verify all flight modes (if configured)

2. **First Test Flight**:
   - Choose safe, open location
   - First hover test (LOS - line of sight)
   - First FPV test flight (short duration)
   - Evaluate performance (handling, video quality, flight time)

3. **Digital Upgrade Decision**:
   - If analog performance insufficient: choose MOD-002B (Walksnail) or MOD-002C (HDZero)
   - If analog performance satisfactory: skip digital upgrade, proceed to Phase 2 enhancements

4. **Phase 2 Enhancements** (optional):
   - MOD-003: RGB Arm LEDs
   - MOD-004: VIFLY GPS-mate Power Module

---

## Troubleshooting

### ELRS Receiver Issues

**Receiver not binding**:
- Verify RX/TX wires not swapped (receiver RX → FC T2, receiver TX → FC R2)
- Verify 5V power reaching receiver (check with multimeter)
- Verify UART2 enabled in Betaflight Ports tab
- Try different bind procedure (refer to ELRS documentation)

**No control inputs in Betaflight**:
- Verify receiver protocol set to CRSF in Configuration tab
- Verify receiver is bound (LED behavior)
- Check RX/TX wiring again

**Weak RSSI or range issues**:
- Verify antennas are intact and properly positioned
- Check for antenna blockage (carbon fiber, metal parts)
- Ensure antennas at ~90° diversity angle

### Analog Video Issues

**No video feed**:
- Verify antenna connected (CRITICAL - VTX damage if not connected)
- Verify VTX powered (check LED indicator)
- Verify camera powered (check for lens focus/activity)
- Check camera to VTX wiring (video signal connection)
- Try different channel/band on goggles

**Poor video quality/static**:
- Check for loose antenna connection
- Verify antenna not damaged
- Check for electrical interference (poor grounding)
- Verify camera lens clean and focused

**No OSD display**:
- Verify UART1 enabled for VTX in Betaflight Ports tab
- Verify SmartAudio/Tramp protocol selected correctly
- Check VTX TX wire to R1 pad connection
- Verify OSD enabled in Betaflight Configuration tab

**VTX not responding to commands**:
- Verify SmartAudio/Tramp wiring correct (VTX TX → FC R1)
- Try alternative UART (UART3 on R3/T3)
- Check VTX documentation for correct protocol

**TX800 overheating or shutting down**:
- Verify antenna connected (overheating indicates no antenna load)
- Check for short circuit to frame/FC
- Verify standoffs providing proper clearance
- Check voltage within TX800 specifications

---

## Safety Notes

### Critical Safety Rules

1. **NEVER power VTX without antenna connected** - Instant damage to VTX
2. **Always use proper standoffs for VTX** - Prevents shorting and damage
3. **Test with props off first** - Verify motor directions and control before flight
4. **Check for loose parts before powering** - Prevent shorts and damage
5. **Use proper battery connector** - XT60 on RD-59, verify polarity
6. **Monitor battery voltage** - Never discharge 6S LiPo below 3.3V per cell (19.8V total)

### Battery Safety

- **6S LiPo voltage ranges**:
  - Fully charged: 25.2V (4.2V per cell)
  - Nominal: 22.2V (3.7V per cell)
  - Low alarm: 21.0V (3.5V per cell) - land immediately
  - Critical: 19.8V (3.3V per cell) - risk of permanent damage

- Set low voltage alarm in Betaflight OSD (recommend 21.0V for 6S)

---

## Reference Documents

- **Modifications Log**: [RD-59_Modifications_Log.md](RD-59_Modifications_Log.md)
- **As-Built Parts List**: [RD-59_AsBuilt_Parts_List.md](RD-59_AsBuilt_Parts_List.md)
- **Build Timeline**: [RD-59_Build_Timeline.md](RD-59_Build_Timeline.md)
- **Factory Specs**: [reference/Nazgul_DC5_ECO_Factory_Specs.md](reference/Nazgul_DC5_ECO_Factory_Specs.md)
- **FC Wiring Diagram**: [reference/20231227025325BF14871BLITZATF435FCWiringDiagram20231005.pdf](reference/20231227025325BF14871BLITZATF435FCWiringDiagram20231005.pdf)

---

**Document Status**: Pre-Installation Planning Complete
**Last Updated**: 2025-11-10
**Next Update**: After Phase 1 installation completion

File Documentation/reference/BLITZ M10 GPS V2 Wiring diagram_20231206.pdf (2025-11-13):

# FPV GPS Module

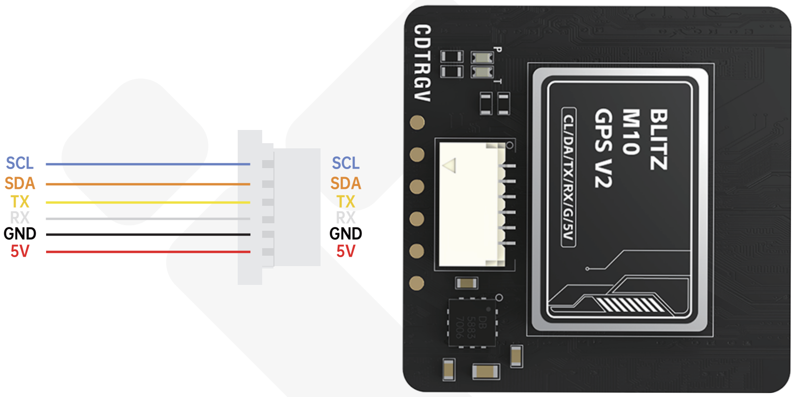
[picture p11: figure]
SCL SDA TX RX GND 5V
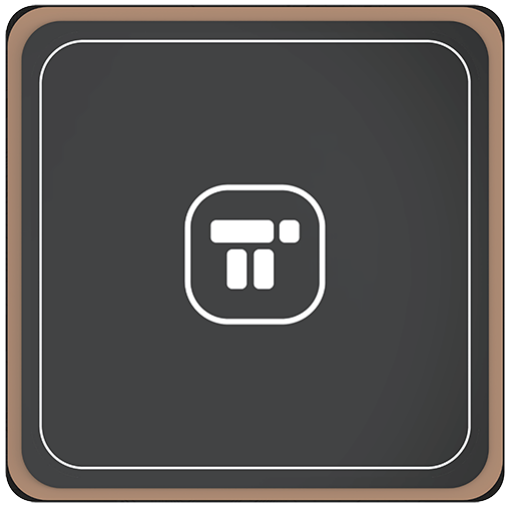
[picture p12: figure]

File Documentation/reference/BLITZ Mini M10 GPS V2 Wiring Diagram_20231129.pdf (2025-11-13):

# FPV GPS Module

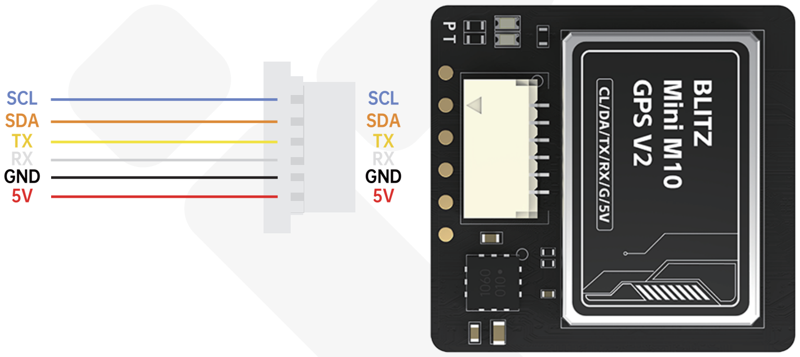
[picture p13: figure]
SCL SDA TX RX GND 5V
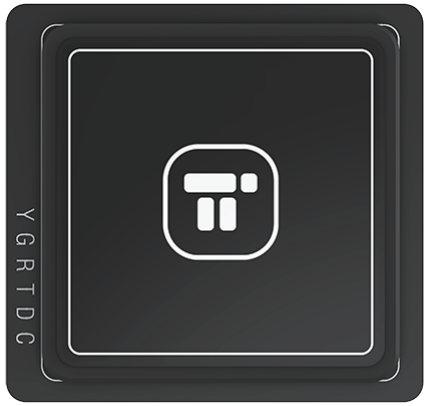
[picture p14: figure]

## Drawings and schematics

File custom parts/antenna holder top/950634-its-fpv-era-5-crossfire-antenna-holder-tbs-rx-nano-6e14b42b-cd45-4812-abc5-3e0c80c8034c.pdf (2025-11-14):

## IT'S FPV - ERA 5" Crossfire Antenna

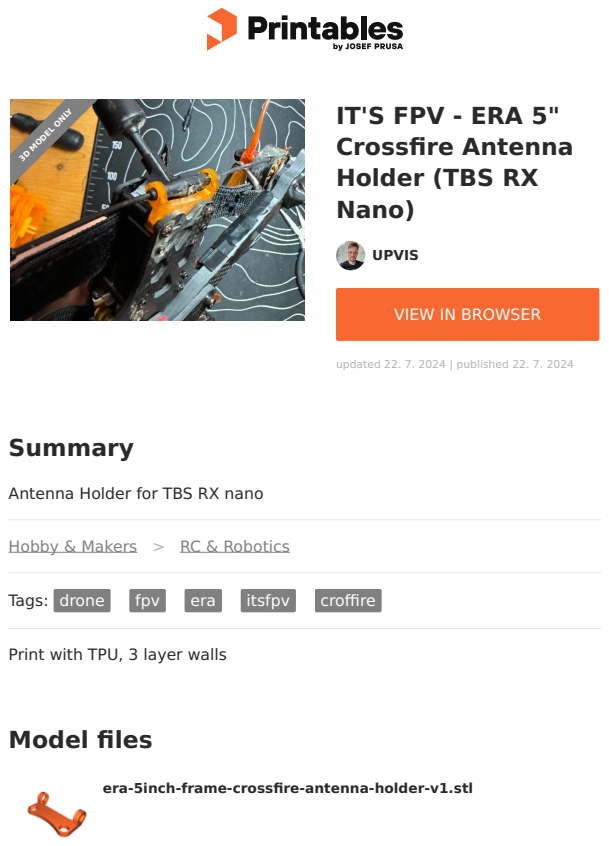
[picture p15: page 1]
Model files; Summary; Tags:; drone; fpv; era; itsfpv; croffire; UPVIS; updated 22. 7. 2024 | published 22. 7. 2024; 3D MODEL ONLY

Holder (TBS RX
Nano)

VIEW IN BROWSER (https://printables.com/model/950634-its-fpv-era-5-crossfire-antenna-holder-tbs-rx-nano)

Antenna Holder for TBS RX nano

Hobby & Makers (https://printables.com/model?categoryId=48) > RC & Robotics (https://printables.com/model?categoryId=64)

Print with TPU, 3 layer walls

era-5inch-frame-crossfire-antenna-holder-v1.stl

## License

This work is licensed under a
Creative Commons (4.0 International License)

Attribution (http://creativecommons.org/licenses/by/4.0/)

✖ | Sharing without ATTRIBUTION
✔ | Remix Culture allowed
✔ | Commercial Use
✔ | Free Cultural Works
✔ | Meets Open Definition

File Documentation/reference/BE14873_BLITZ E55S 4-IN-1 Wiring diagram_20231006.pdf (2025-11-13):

# BLITZ E55S 4-IN-1

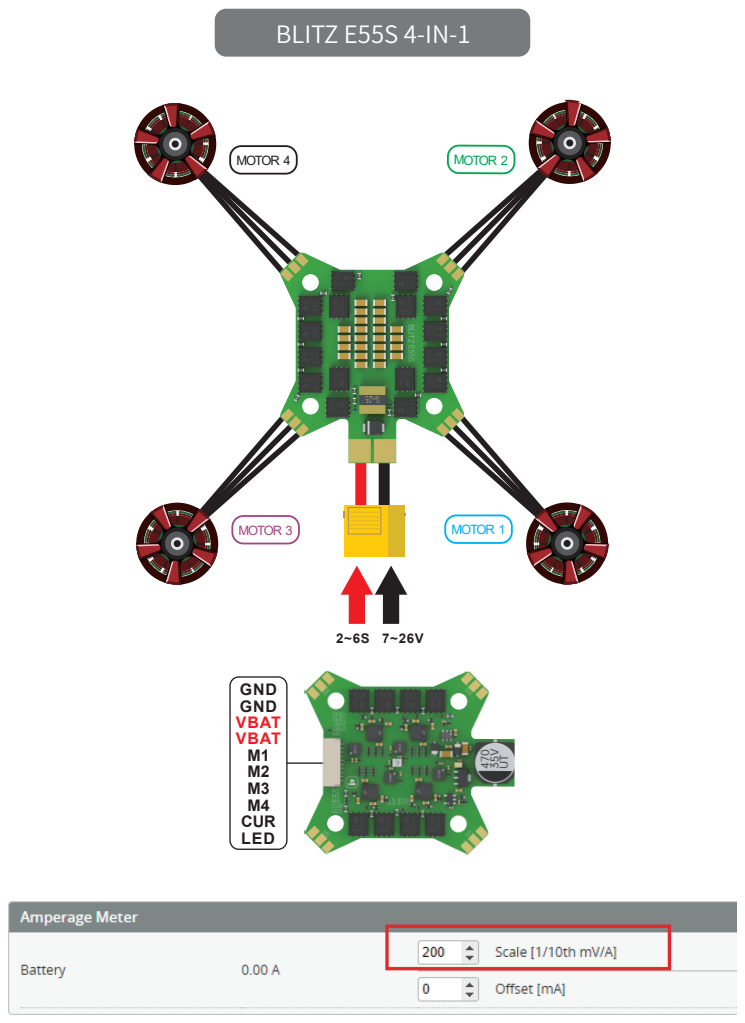
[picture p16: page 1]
MOTOR 4; MOTOR 2; MOTOR 3; MOTOR 1; VBAT; GND GND; LED; M1 M2 M3 M4 CUR

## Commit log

2025-11-10 Add comprehensive documentation for RD-59 "Nazgul" build, incidents, modifications, and factory specs
    - Created RD-59_Build_Timeline.md to outline project history and future plans
    - Established RD-59_Incident_Log.md to track incidents (currently none)
    - Developed RD-59_Modifications_Log.md to document planned modifications and installation status
    - Compiled README.md as an index for all documentation related to RD-59
    - Added reference document for factory specifications: Nazgul_DC5_ECO_Factory_Specs.md
2025-11-13 Refactor code structure for improved readability and maintainability
    [Front Bumber TPU nazgul5 dc eco.stl, Front Bumber TPU.3mf, PP_Camera+mount.3mf]
2025-11-14 feat: initialize project with package.json for RD-59 Nazgul drone
    [Front Bumber TPU.3mf, RadioMasterRp1Mount.stl, era-5inch-frame-crossfire-antenna-holder-v1.stl]
2025-11-18 docs: add GitHub Issues & Project Management workflow to CLAUDE.md
    Add comprehensive documentation for dual-track system:
    - Markdown docs for detailed archive
    - GitHub Issues for cloud-based task tracking
    - Project board #13 for visual management
    Includes:
    - Issue label system (incident, modification, parts-ordered, etc.)
    - When to create issues workflow
    - Integration between issues and Markdown docs
    - Common gh CLI commands reference
    - Issue lifecycle and best practices
    Future Claude instances will now automatically use GitHub Issues
    alongside Markdown documentation for RD-59 project tracking.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
2025-11-18 docs: add issue assignment to GitHub workflow in CLAUDE.md
    Update issue creation workflow to include:
    - Assign issues to operator (spydmobile) by default
    - Add --assignee flag to gh issue create examples
    - Add gh issue edit --add-assignee command
    - Add gh issue list --assignee filter example
    Also assigned existing issues #1 and #2 to spydmobile.
2025-11-18 feat: add GitHub milestones for RD-59 project tracking
    Created four milestones to track major RD-59 goals:
    1. Working Video - FPV video system operational
    2. Working GPS - GPS configured and acquiring satellites
    3. Ready To Fly - All critical systems airworthy
    4. Maiden Flight - First successful flight
    Updated CLAUDE.md to document:
    - Milestone structure and descriptions
    - When to assign issues to each milestone
    - gh CLI commands for milestone management
    - Issue creation workflow includes milestone assignment
    Assigned existing issues to milestones:
    - Issue #1 (ELRS receiver) → Ready To Fly
    - Issue #2 (video system) → Working Video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
2025-11-18 docs: add GitHub Project Management setup guide
    Create installGHPM.md - a complete prompt guide for setting up
    the same GitHub project management system on other drone projects.
    The guide includes:
    - Prerequisites and overview
    - Complete copy-paste prompt for Claude Code
    - Step-by-step instructions for:
    * GitHub CLI installation
    * Custom issue labels
    * Project board creation
    * Milestone setup
    * Initial issue creation
    * CLAUDE.md documentation
    - Expected outcomes and customization options
    - Usage instructions and maintenance tips
    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
2025-11-18 refactor: version and clean up installGHPM guide (v1.01)
    - Add version number to filename (installGHPM_v1.01.md)
    - Fix all markdown linting warnings:
    * Add blank lines around all lists (MD032)
    * Convert emphasis to proper headings for START/END OF PROMPT (MD036)
    * Wrap bare URLs in angle brackets (MD034)
    All markdownlint warnings resolved. Document follows clean code standards.
